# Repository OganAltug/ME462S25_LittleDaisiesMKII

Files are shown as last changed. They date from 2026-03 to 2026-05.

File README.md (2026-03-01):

Repository for ME462 - Mechatronics Design course at METU

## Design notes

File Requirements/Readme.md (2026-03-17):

Locking Mechanism:
- Mechanical:
  - The mechnism must be able to switch tools in less than 30 seconds.    
  - The mechanism must connect two sides without permanent fastening.
  - The mechanism must withstand axial load of 5kgs.
  - The mechanism must withstand torsional load of 6Nm.
  - The mechanism must withstand monment of 3Nm.
  - The mechanism must not shift more than 1 mm and 6 degrees in repetative usage.
  - The mechanism must allow manual disengage in less than 5 seconds in case of emergency.
  - The mechanism must be suitable to manufacture with basic robotics lab tools.
  - The mechanism must not disangage during the opertaion.
  - The total weight of the locking mechanism must be less than 2N (In Earth)
- Electrical Interface:
  - The mechanism must allow 23 consecutive hours of operation.
  - The electrical interface must carry the 8 electrical output of the Robot arm between two locking pieces.
  - The electrical interface should be modular on the robot side. (to adjust arms other than ur5)
  - The electrical interface must succesfully trasmit electricity for every engage.

Toolbox:
- Mechanical:
  - The toolbox must house more than 3 tool.
  - The Toolbox must hold the tools firmly.
  - The Toolbox must allow user to disengage tools less than 60 secs in manual operation.
  - The Toolbox must be in the reach of the robot arm.
  - The Toolbox position must be changeable.
  - The Toolbox must not block the motion of the robot arm.
- Electrical:
  - The Toolbox must be able to charge active grippers.
  - The Toolbox must prevent over-undercharge of the active tool batteries.
  - The Toolbox must indicate if the active gripper is charged or not to the user.
  - The Toolbox must communicate with the arm to inicate the charge status of the active grippers.
  - The Toolbox PCB must be maximum of two layers.
  - The Toolbox PCB components must be found in web less than 3 consecutive searches.

Handler:
- PCB:
  - The Handler PCB must have a port to connect Toolbox to charge itself.
  - The Handler must have a indicator to show its battery level to user.
  - The Handler must communicate with the arm to inicate the charge status of itself.
  - The Handler PCB must be maximum of two layers.
  - The Handler PCB must be smaller than 8x8 cm in size.
  - The handler PCB components must be found in web less than 3 consecutive searches.

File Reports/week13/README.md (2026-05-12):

# Weekly Report: LittleDaisiesMKII - Week 13

**Date Range:** May 5 - May 12
---
## 📊 Team Performance & Scoring

*Evaluation of specific tasks and deliverables based on project requirements.*
| Deliverable / Metric | Score | Notes |
| :--- | :--- | :--- |
| Robot control and sand writing  | 10/10 | We are able to write onto the sand  |
| Checking the new hardware given | 8/10 | Mini esp and the camera is checked  |
| Gripper force control | 7/10 | both force with current and fsr is tried|
| Image Processing | 5/10 | an object is followed via servo no updat eon arucos |
| TutanKhamun Gripper Assembly | 10/10 | TutanKhamun the Heybetli is Assembled |
| **Total Score**  | **40/50** | **Avg: 8/10** |
---

## 🤝 Meeting Notes

### May 11 - Group Meeting

**Key Discussion Points:**
Everyone is explained what they have done for the past week. 
* Buğra worked on image processing on Rasppery Pi, and successfully followed and object (human) by tip of the servo. He also tried to work with FSR, and sucessfully implemented the FSR force control to the 2f-85 gripper machanism. Finally, he tried to work with the given esp32 with integrated camera but did not like the output feed quality.
* Some search about the head is done.
  - [IDEA 1](https://www.youtube.com/shorts/ejHmpcbf4PA)<br>
  - [IDEA 2](https://www.youtube.com/shorts/wkof60aqg6w)<br>
  - [IDEA 3](https://www.youtube.com/shorts/eSnn20z8AxQ)<br>
  - [IDEA 4](https://www.youtube.com/watch?v=IT1uBUsOmUY)<br>
  - [IDEA 5](https://www.youtube.com/shorts/pm9Umdwg9uo)<br>
  - [IDEA 6](https://www.youtube.com/shorts/5SJYWTB2Nf4)<br>
  - [IDEA 7](https://youtube.com/shorts/Qu2Ccx3YggI?si=xmM9Od8_wPeU3PLN)<br>
  - [IDEA 8](https://youtube.com/shorts/5SJYWTB2Nf4?si=HgB3RJdVCw9v34qi)<br>
  - [IDEA 9](https://youtube.com/shorts/ARHM2iDbWIY?si=fSSAW8HbxofMi2Qx)<br>
  - [IDEA 10]<br>
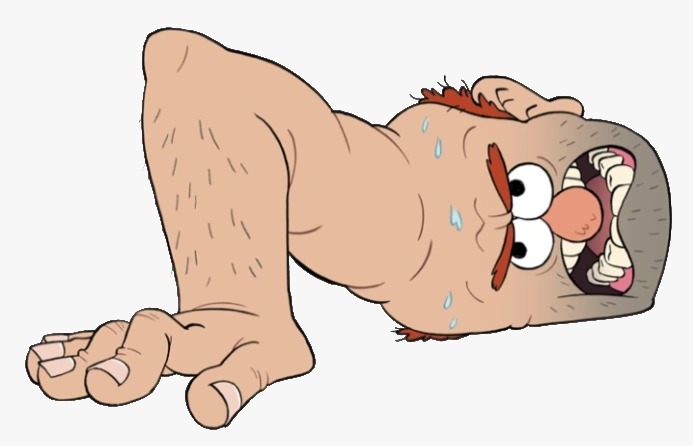
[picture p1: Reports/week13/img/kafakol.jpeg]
Kafa Kol
    <br>
  - [IDEA 11]<br>
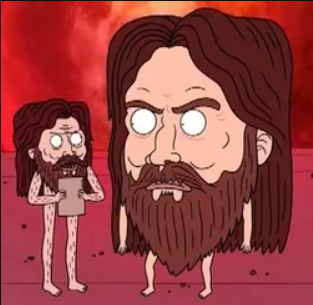
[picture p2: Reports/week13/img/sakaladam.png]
Sakal Adam
    
* Ogan kept working on the robot control. He finalized the sand-writing process, and now we are able to write on the sand. He also created a docker file for other members to efficiently and easiliy get into the robot control. Thanks Ogan.
* Naci kept wroking on the gripper mechanism, electronics and software. He mainly focussed on the force control via current readings, however he faced with some problems. Currently the current-force control is not as reliable as we wanted. He also gathered the documentations and files about the gripper so that other members of the group can succesfully get into the gripper part.
* Deniz, wrote this meeting minute.
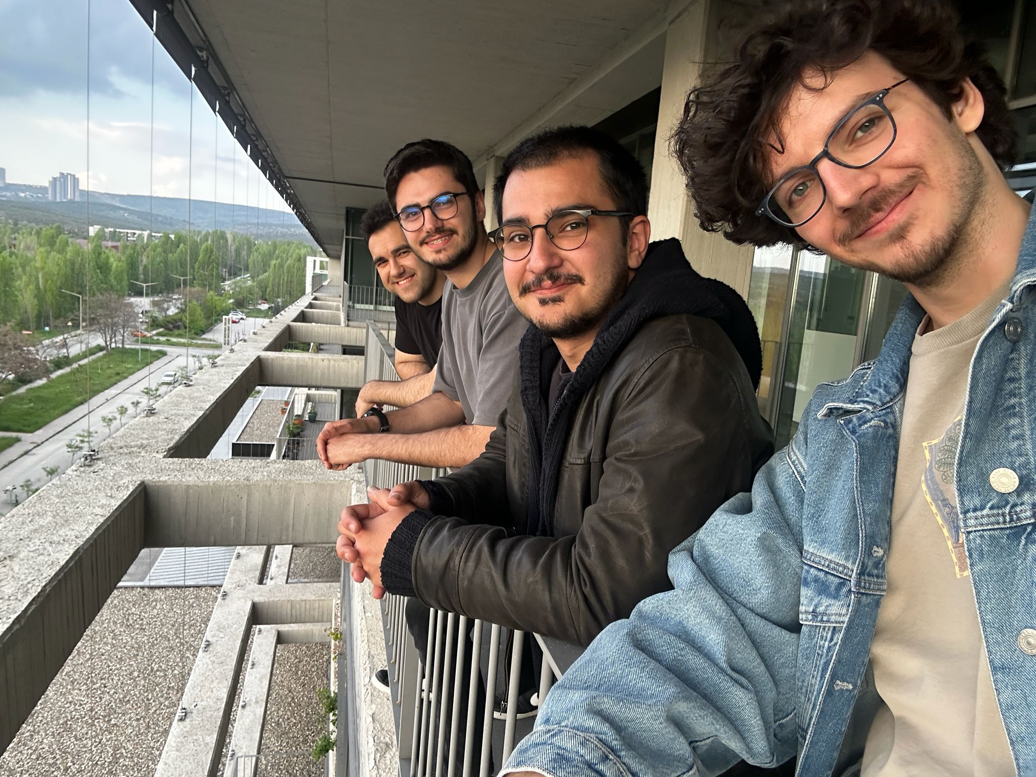
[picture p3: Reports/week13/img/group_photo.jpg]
Group Photo

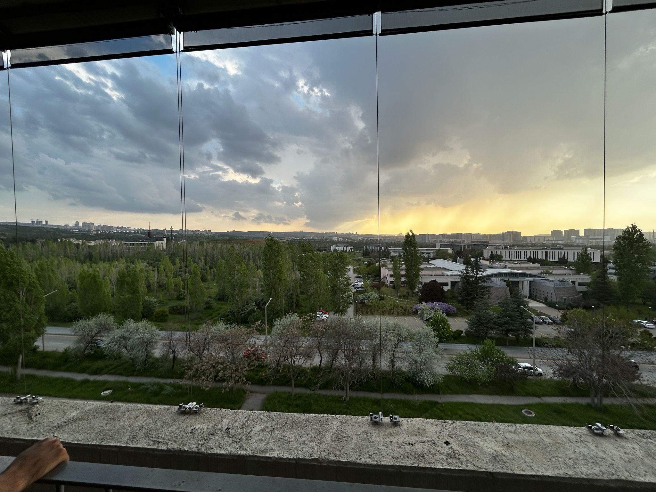
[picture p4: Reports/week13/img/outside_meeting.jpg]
Outside Meeting

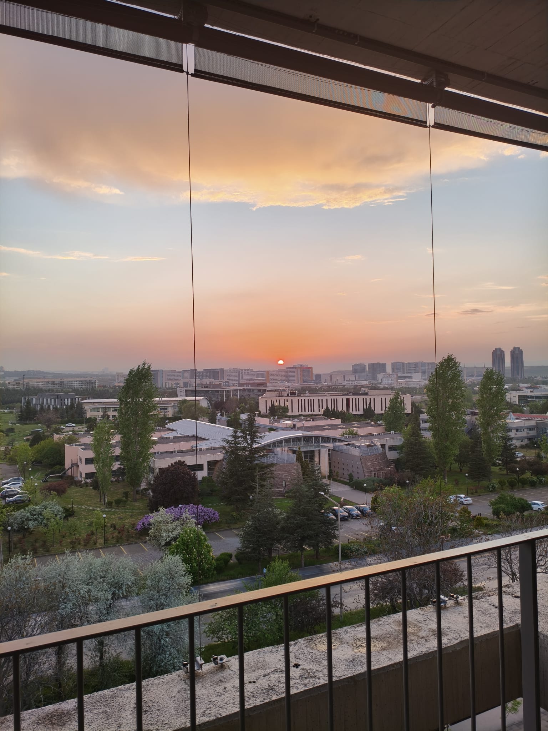
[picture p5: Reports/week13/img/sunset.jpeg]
Sunset

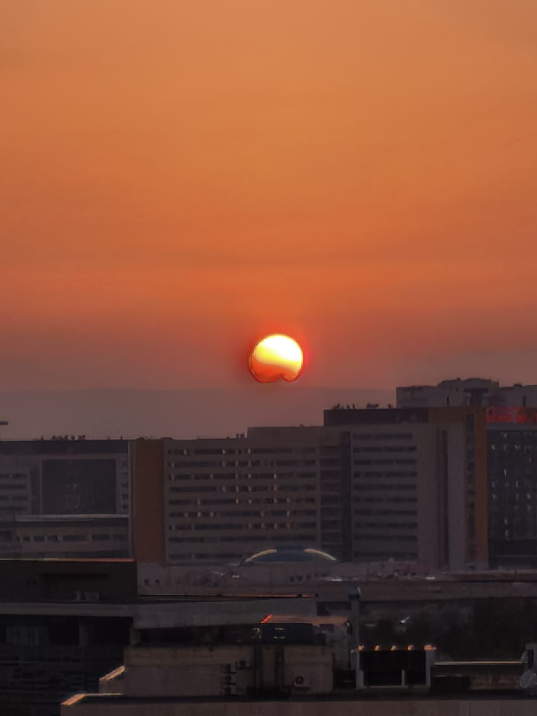
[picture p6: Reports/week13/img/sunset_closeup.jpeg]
Sunset Closeup

## 🖼️ Visual Documentation & Progress
* Writing Little Daisies on the sandpool
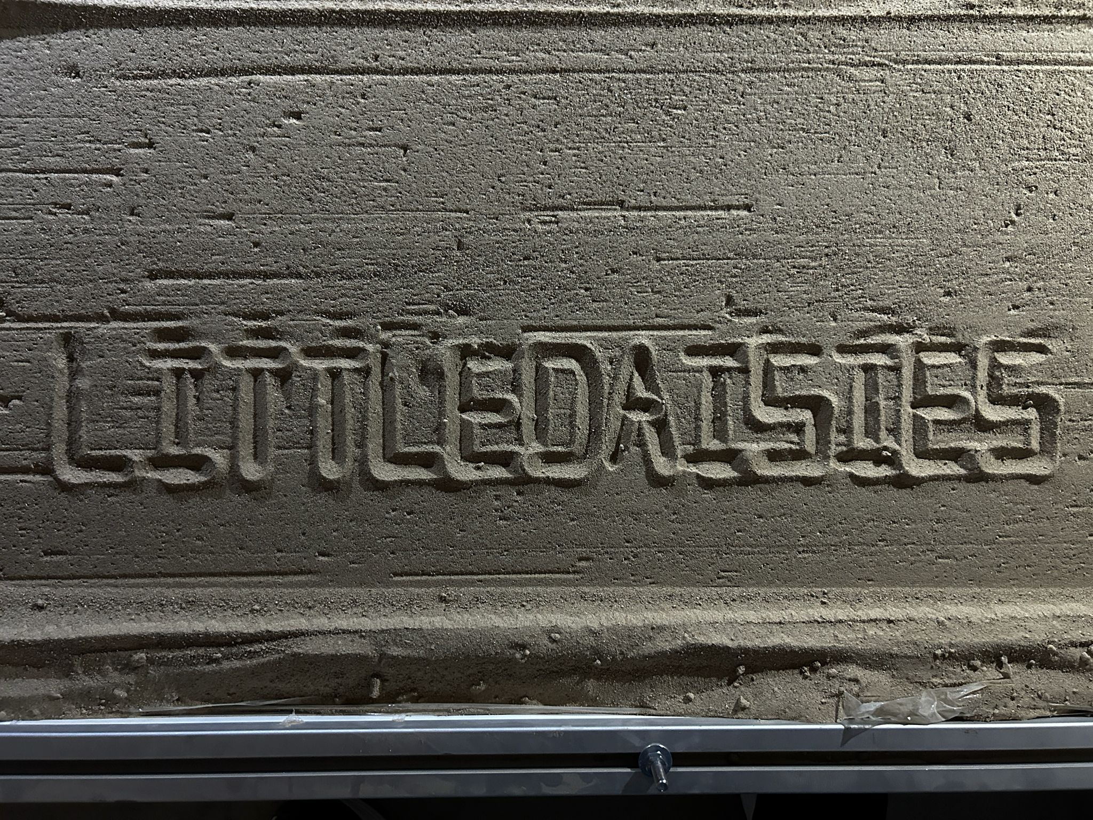
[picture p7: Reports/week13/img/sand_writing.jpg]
Little Daisies on the Sand

* Feed from esp32
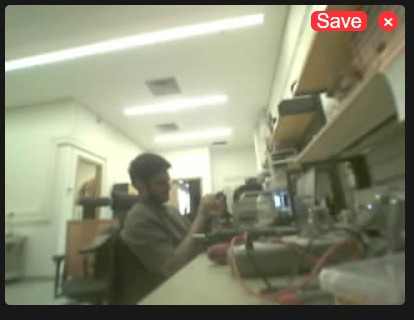
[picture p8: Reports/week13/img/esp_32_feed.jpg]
Feed from esp32

* Tutan Khamun Assembly
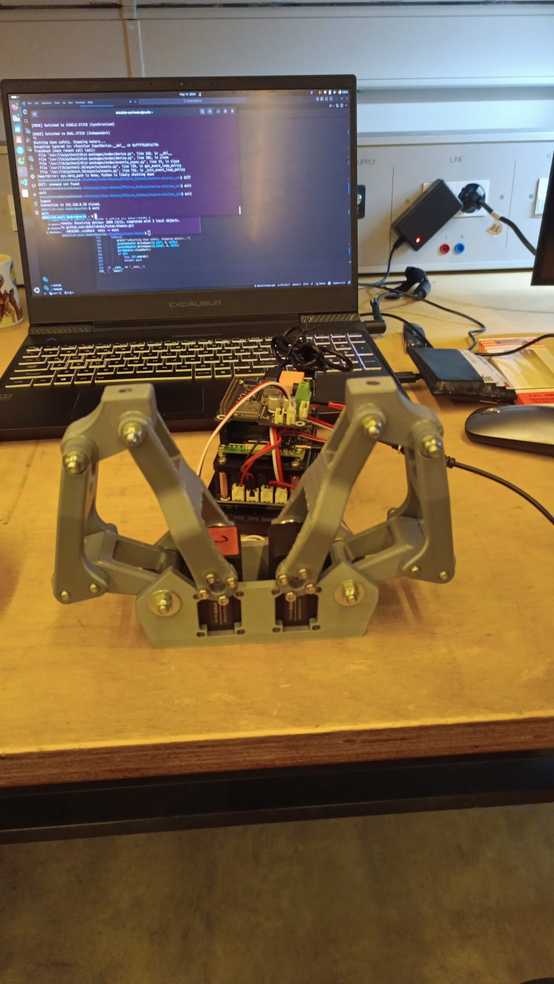
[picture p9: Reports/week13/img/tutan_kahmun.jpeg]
tutan_kahmun

* Plots from Tutan-Khamun current-force control
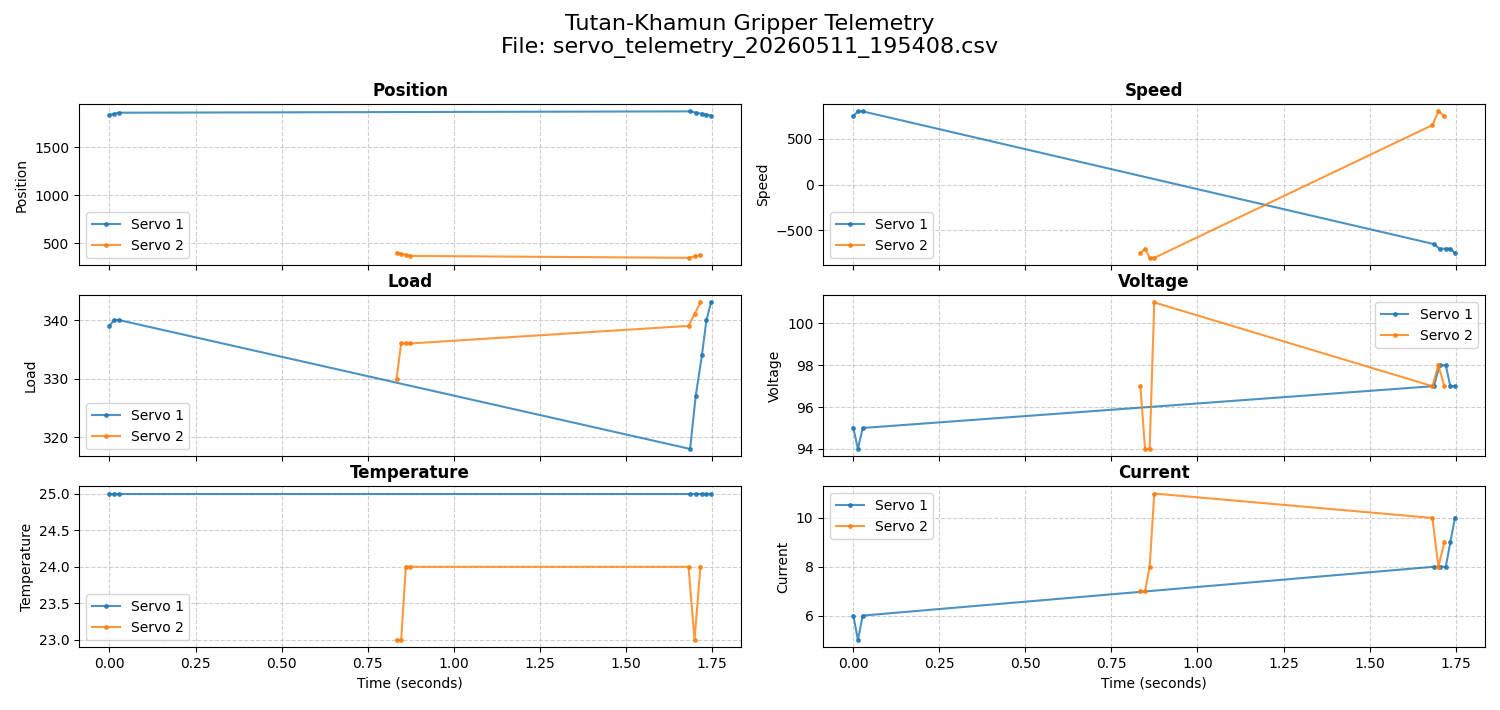
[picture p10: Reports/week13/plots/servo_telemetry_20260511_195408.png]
Only Threshold

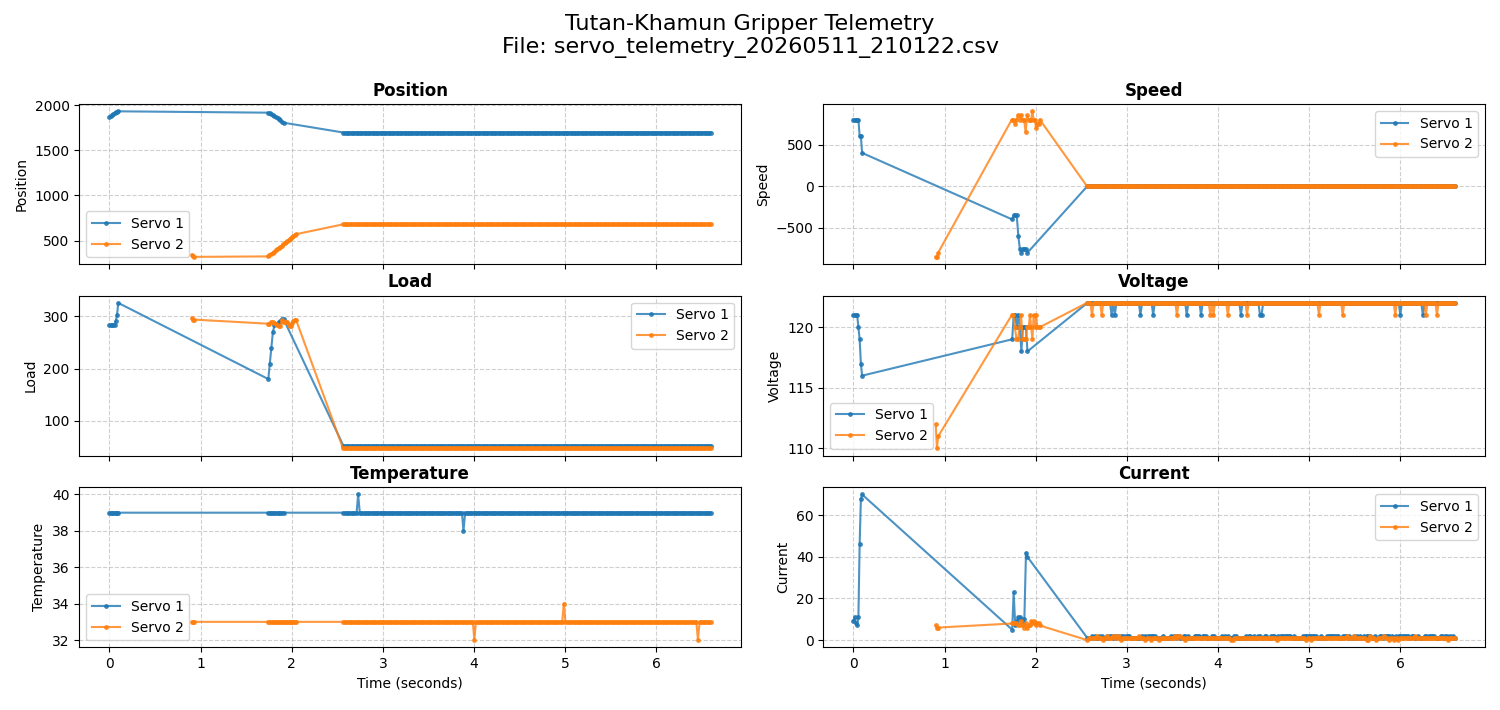
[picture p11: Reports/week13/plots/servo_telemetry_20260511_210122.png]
Delta Threshold

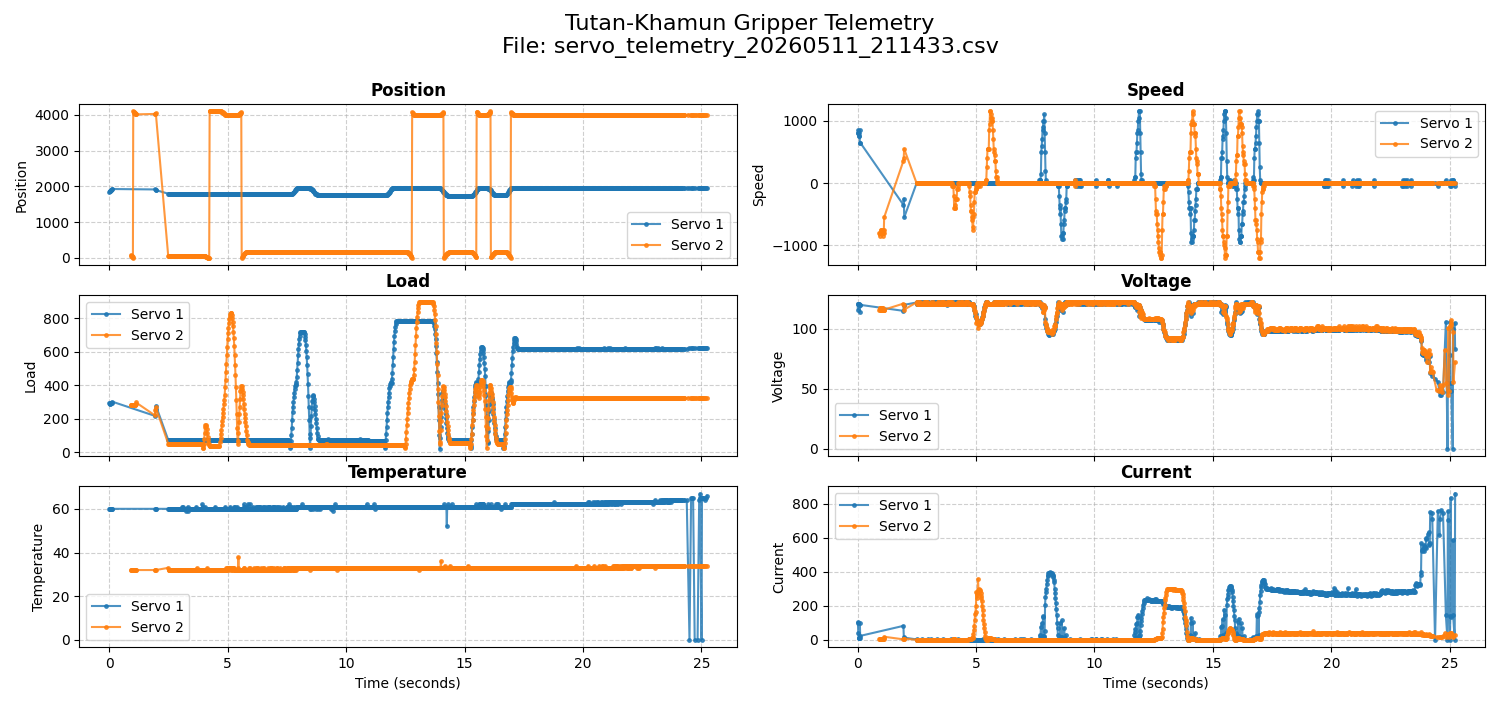
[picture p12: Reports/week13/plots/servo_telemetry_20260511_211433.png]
Burn-out


## 🔗 Documentation Links
[Robot Control Docker Repo](https://github.com/OganAltug/ME462ZenPoolWorkspace)

## 📝 To-Do List (Action Items)

### Immediate Priority

- [ ] **Hardware:** Redesign [Component] based on recent test results.
- [ ] **Software:** Implement [Feature] in simulation environment.
- [ ] **Manufacturing:** Obtain [Material/Part] and fabricate [Item].

### Research & Documentation

- [ ] **Research:** Investigate [Mechanism/Protocol] alternatives.
- [ ] **Reports:** Document [Naming Convention/Interface Requirements].
- [ ] **Maintenance:** Update README with latest links and media.

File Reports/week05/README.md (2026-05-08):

# Weekly Report: LittleDaisiesMKII - Week 5

**Date Range:** March 10 - March 16, 2026

## 📊 Team Performance & Scoring

*Evaluation of specific tasks and deliverables based on project requirements.*

| Deliverable / Metric | Score | Notes |
| :--- | :--- | :--- |
| Naming Convention | 6/10 | Revision in progress |
| Meeting Minutes | 10/10 | Completed |
| Locking Interface PCB Requirements | 5/10 | Further detail needed |
| Locking Interface Mech. Requirements | 8/10 | Well-defined |
| Robot Control | 7/10 | Progressing |
| Zen Tool (Rotated by π/2) | 8/10 | Design and manufacturing |
| **Total Score** | **44/60** | **Avg: 7.33/10** |

---

## 🤝 Meeting Notes

### Monday Meeting

**Key Discussion Points:**

* **Decisions:** Naming convention finalized and documented via visual reference.
* **Hardware Progress:** Designed and manufactured the first version of the Zen Tool; designed a sieve for the tool.
* **Simulation & Control:** Successfully tested basic UR5e pose-to-pose motion using MuJoCo and Robotictoolbox.
* **Manufacturing:** Discussed laser-cut PCB manufacturing details, including Xtool and KiCAD settings and via manufacturing ideas.
* **Mechanism Brainstorming:** Evaluated kinematic coupling ideas including self-releasing grapples, bearing-style ball locks, and active locking via the UR5e power cable.

### Tuesday Meeting

* **Electronic Specs:** Researched microcontroller features including Wi-Fi support, deep-sleep modes, and Wi-Fi wake capabilities.
* **Communication:** Initiated review of communication protocols.

---

## 🖼️ Visual Documentation & Progress

*Capturing hardware builds and simulation results.*

* **Naming Convention:**
  `<img src="./img/name_convention.jpeg" alt="Name Convention" width="600"/>`
* **Zen Tool Mounted:**
  `<img src="./img/ZenToolMounted.jpeg" alt="ZenToolMounted" width="300"/>`
* **Sieve Design:**
  `<img src="./img/sieve.jpeg" alt="Sieve Design" width="300">`
* **MuJoCo Simulation:**
  `<img src="./img/mujoco.gif" alt="Mujoco Sim" width="400">`

---

## 🔗 Documentation Links

* [Tool Interface/Handler Requirements](../../Requirements/Readme.md)
* [PCB Manufacturing Report](../../PCB/HowToLaserPCB.md)
* [Locking Mechanism Ideas (Google Doc)](https://docs.google.com/document/d/15yzl3hxYkYvtqdlGrBOaPBBX_cD7uZbD/edit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)

---

## 📝 To-Do List (Action Items)

### Immediate Priority

- [ ] **Hardware:** Redesign/tweak Zen Tool based on structural and functional testing.
- [ ] **Hardware:** Manufacture sieve (obtain wire first).
- [ ] **Software:** Implement Zen Tool into MuJoCo and test.
- [ ] **Electronics:** Research PCB components and UR5e serial connection details.

### Research & Documentation

- [ ] **Research:** Look into alternative simulators and quick connect/release mechanisms.
- [ ] **Reports:** List all potential locking mechanisms in a dedicated file and write interface requirements.
- [ ] **Maintenance:** Document the naming convention and add links to the "README.md".

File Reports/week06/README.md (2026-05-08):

# Weekly Report: LittleDaisiesMKII - Week 6

**Date Range:** March 17 - March 23, 2026

## 📊 Team Performance & Scoring

*Evaluation of specific tasks and deliverables based on project requirements.*

| Deliverable / Metric | Score | Notes |
| :--- | :--- | :--- |
| Meeting Minutes | 10/10 | Completed |
| Communication Protocols | 0/10 | Not discussed yet |
| Numeric Proofs for Design Choices | 0/10 | Pending for decision matrix justification |
| Toolbox & Locking Requirements (Mech) | 8/10 | Concepts generated; full brainstorm pending |
| Toolbox & Locking Requirements (Elec) | 0/10 | Toolbox not yet discussed |
| Artsy Tool First Design | 5/10 | Designs exist; no progress this week |
| Tweak & Manufacture Design | 5/10 | Printed model exists; improvements pending  |
| **Total Score** | **28/70** | **Avg: 4.0/10 (Ramadan Fest)** |

---

## 🤝 Meeting Notes

### Monday Meeting

**Key Discussion Points:**

* **Decisions:** Documented naming convention and compiled a comprehensive list of locking mechanisms.
* **Mechanism Brainstorming:** Focused on passive locking mechanism drafts (Ogan, Naci, Buğra, and Ahmet's ideas). Passive ideas are prioritized to determine if they suffice before moving to active systems.
* **Review:** Inspected individual team member concepts to prepare for the upcoming decision matrix.

### Tuesday Meeting

* **Design Ideas:** Explored magnetic locking (strong tensile, weak shear) and ball magnets for Buğra’s Design II.
* **Toolbox Concepts:** Discussed a non-rigidly attached toolbox using camera-based position detection.
* **Mechanical Innovation:** Discussed a reusable "dübel" concept and a 90-degree movement version of the push-to-turn design.
* **Future Outlook:** Initiated preliminary talk on active grippers.

---

## 🖼️ Visual Documentation & Progress

*Capturing hardware builds and simulation results.*

* **Current Prototype:**
  `<img src="./img/printed_model.jpeg" alt="Printed Model" width="300"/>`
* **Locking Concepts:**
  `<img src="./img/locking_drafts.jpeg" alt="Locking Mechanism Drafts" width="600"/>`

---

## 🔗 Documentation Links

* [Naming Convention Document](../../Requirements/NamingConvention.md)
* [Locking Mechanisms List](../../Requirements/LockingMechanisms.md)
* [Brainstorming Minutes](../../Minutes/BrainstormingNotes.md)

---

## 📝 To-Do List (Action Items)

### Immediate Priority

- [ ] **Hardware:** Manufacture the Zen tool sieve (obtain wire first).
- [ ] **Control:** Start controlling the robot arm.
- [ ] **Analysis:** Conduct the decision matrix for the generated locking drafts.
- [ ] **Design:** Finalize passive locking requirements and final drafts.

### Research & Documentation

- [ ] **Strategic:** Depending on decision matrix, start toolbox requirements OR generate active locking ideas.
- [ ] **Manufacturing:** Manufacture a full set of Zen tools.
- [ ] **Brainstorming:** Set toolbox ideas once requirements are finalized.

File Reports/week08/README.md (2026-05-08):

# Weekly Report: LittleDaisiesMKII - Week 8

**Date Range:** March 31 - April 6, 2026

---

## 📊 Team Performance & Scoring

*Evaluation of specific tasks and deliverables based on project requirements.*

| Deliverable / Metric | Score | Notes |
| :--- | :--- | :--- |
| Robot Arm Control | 7/10 | Simulations started; UR5 testing with Zen tool |
| Locking Mechanism Trial / DoveTail | 4/10 | Dovetail/pin printed; wedge/ball design ready  |
| Zen Tool Trial | 8/10 | Controlled UR5 with Zen tool |
| **Total Score** | **19/30** | **Avg: 6.33/10** |

---

## 🤝 Meeting Notes

### Weekly Progress

**Key Discussion Points:**

* **Robot Arm Control:** Ogan initiated simulation work [cite: 5]. Ahmet Deniz performed physical testing using the Zen tool and the UR5 arm
* **Mechanism Development:** The dovetail and pin locking mechanism was printed and tested for initial fit and function
* **New Designs:** A wedge-based locking mechanism utilizing a ball/bearing was successfully designed
* **Zen Tool Integration:** Demonstrated successful control of the UR5 system specifically utilizing the Zen tool interface

---

## 📝 To-Do List (Action Items)

### Immediate Priority

- [ ] **Control:** Continue progress on Robot Arm Control systems.
- [ ] **Design:** Perform optimization of the Dovetail & Pin Locking Mechanism.
- [ ] **Development:** Create an initial design for the tool box based on the current locking mechanism for simple testing.

### Research & Documentation

- [ ] **Testing:** Prepare simple testing procedures for the new toolbox design.

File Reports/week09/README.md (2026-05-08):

# Weekly Report: LittleDaisiesMKII - Week 9

**Date Range:** April 7 - April 13, 2026

---

## 📊 Team Performance & Scoring

*Evaluation of specific tasks and deliverables based on project requirements.*

| Deliverable / Metric | Score | Notes |
| :--- | :--- | :--- |
| Robot Arm Control | 9/10 | Progress in simulations; documentation hurdles |
| Locking Mechanism Optimization | 10/10 | Concept nearly finalized and optimized |
| Initial Toolbox Design | 8/10 | Multiple concepts designed; charging research done |
| **Total Score** | **27/30** | **Avg: 9.0/10** |

---

## 🤝 Meeting Notes

### Weekly Progress

**Key Discussion Points:**

* **Robot Arm Control:** Ogan continued simulation progress, though limited documentation for MuJoCo and ROS has presented challenges. Potential shifts to C++ may be required.
* **Mechanism Optimization:** Deniz further refined the dovetail and pin locking mechanism, nearly finalizing the concept. Buğra proposed an alternative pin system designed for better charging connectivity.
* **Toolbox Design:** Naci and Buğra developed separate toolbox concepts, with Buğra’s design featuring rotational springs and moving arms for stability.
* **Charging Investigations:** Evaluated Pogo pin connectors (favored for ease of control), wireless Magsafe-style chargers (financial and alignment concerns), and standard cable connectors (rejected due to high precision requirements).

---

## 🖼️ Visual Documentation & Progress

*Capturing hardware builds and simulation results.*

### 🎥 Media (Videos)

* **Arm Control Simulation:**
  [Video 1](./media/armcontrol_ogan.mp4)
* **Locking Mechanism Optimization:**
  [Video 1](./media/locking_deniz1.mp4)
  [Video 2](./media/locking_deniz2.mp4)

### 📷 Images

* **Optimized Locking Pin:**
  `<img src="./img/locking_deniz3.jpeg" alt="locking_deniz3" width="320"/>`
* **Naci's Toolbox Concept:**
  `<img src="./img/locking_bugra1.jpeg" alt="toolbox_naci" width="320"/>`
* **Buğra's Toolbox Design:**
  `<img src="./img/locking_bugra2.jpeg" alt="locking_bugra2" width="320"/>`

---

## 🔗 Documentation Links

* [Toolbox Charging Research](../../Research/ChargingOptions.md)
* [Dovetail Finalization Report](../../Design/DovetailFinal.md)
* [Active Tool Concepts](../../Design/ActiveTools.md)

---

## 📝 To-Do List (Action Items)

### Immediate Priority

- [ ] **Control:** Dedicate more effort to Robot Arm control to overcome documentation hurdles.
- [ ] **Testing:** Test the first toolbox version using the final locking mechanism version.
- [ ] **Design:** Update the mechanical systems of the toolbox based on test results.
- [ ] **Research:** Conduct further searches and discussions regarding charging integration.

### Research & Development

- [ ] **Active Tools:** Discuss and search for active tool implementations (e.g., tracking eye, grippers, or "torNA") to assign PCB specifications.

* **Active Tool References:**
  `<img src="./img/tornaci1.png" alt="torNACİ" width="100"/>` `<img src="./img/tornaci2.png" alt="torNACİ" width="100"/>` `<img src="./img/tornaci3.png" alt="torNACİ" width="100"/>`

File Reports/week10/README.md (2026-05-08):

# Weekly Report: LittleDaisiesMKII - Week 10

**Date Range:** April 14 - April 20, 2026

---

## 📊 Team Performance & Scoring

*Evaluation of specific tasks and deliverables based on project requirements.*

| Deliverable / Metric | Score | Notes |
| :--- | :--- | :--- |
| Robot Arm Control | 8/10 | Ongoing effort; requires more time than expected |
| Toolbox Testing & Updates | 8/10 | Mechanical updates following locking mechanism finalization; charging research ongoing |
| Active Tool Research | 9/10 | Extensive brainstorming and tier-listing of concepts |
| **Total Score** | **25/30** | **Avg: 8.33/10** |

---

## 🤝 Meeting Notes

### 17.04.2026 Meeting

**Key Discussion Points:**

* **Design Ideas:** Discussed Buğra's arm design with springs (focus on buckling) and Ogan's toolbox design with pins.
* **Analysis:** Examined the springback effect of the button.
* **New Concept:** Deniz presented a new tool-changer design utilizing magnets and pins.

### 18.04.2026 Meeting

* **Toolbox Design:** Buğra's design was drawn; Naci updated arm alignment for better performance.
* **Drafting:** Deniz tasked with drawing Ogan's pin-based idea.
* **Simplified Locking:** Buğra proposed a simpler magnetic locking mechanism alternative to the wedge design.

### 20.04.2026 Meeting

* **Concept Brainstorming:** Discussed a wide variety of interactive scenarios:
  * **Zen Sand Artist:** Drawing in sand with a hologram display and recorded tool changes.
  * **Combat/Defense:** Nerf gun defense for sand art, laser "gunslinger" duels, and dart shooting.
  * **Creative/Utility:** Model-making (cutting/gluing), soldering, painting wands, and casino Blackjack dealing.
  * **Personality:** The "Frustrated Organizer" that puts items back or shoots if moved repeatedly.

---

## 🖼️ Visual Documentation & Progress

*Capturing hardware builds and simulation results.*

### 🎥 Media (Videos)

* **Pin Tool Change Test:**
  [Video 1](./media/pin_tool_change.mp4)

### 📷 Images

* **Deniz's Magnet-Pin Concept:**
  `<img src="./img/meet0.png" alt="Magnet Pin Concept" width="320"/>`
* **Buğra's Simple Magnetic Changer:**
  `<img src="./img/bugra_magnet_toolchanger.jfif" alt="Magnetic Changer" width="320"/>`
* **Naci & Team Meeting Logs:**
  `<img src="./img/meet1.jpg" alt="Meeting Note 1" width="320"/>` `<img src="./img/meet2.jfif" alt="Meeting Note 2" width="320"/>`
* **Active Tool Tier List:**
  `<img src="./img/tierlist.png" alt="Tier List" width="320"/>`

---

## 🏗️ Active Tool Design Ideas

A collection of existing and proposed concepts for tool integration:

* **Existing Ideas:** Dragon head fire, lightsaber, Nerf/Nail gun, car-carrying tool.
* **Mechanical Systems:** Hitting mechanisms (Rack & Pinion with spring release), paper cutting (distance measurement & slicing), and sandpaper tools.
* **Grippers:** Adaptive fingers, magnetic, vacuum, and insertion tools.
* **Interactive:** UI screens for Romer navigation and passive tools like kalem/pens for UR5 angle drawings.

## 📝 To-Do List (Action Items)

### Immediate Priority

- [ ] **Hardware:** Update mechanical toolbox designs and perform testing with the final locking mechanism.
- [ ] **Charging:** Continue research and final discussion on toolbox charging integration.
- [ ] **Control:** Dedicate more effort to Robot Arm Control progress.

### Research & Development

- [ ] **PCB Specs:** Assign PCB specifications based on selected active tools.
- [ ] **Manufacturing:** Continue "torNA" progress (Naci).

* **torNA Status:**
  `<img src="./img/tornaci.png" width="80"/>` `<img src="./img/tornaci2.jfif" width="80"/>` `<img src="./img/tornaci3.jfif" width="80"/>` `<img src="./img/tornaci4.png" width="80"/>`

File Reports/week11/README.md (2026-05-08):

# Weekly Report: LittleDaisiesMKII - Week 11

**Date Range:** April 21 - April 27, 2026

---

## 📊 Team Performance & Scoring

*Evaluation of specific tasks and deliverables based on project requirements.*

| Deliverable / Metric | Score | Notes |
| :--- | :--- | :--- |
| Active Tool Discussion | X/10 | One tool decided (Face/Eye); second tool in discussion |
| Gripper Design & Print (Naci)  | X/10 | Includes Raspberry Pi 4 integration |
| Zen Tool Prototyping (Ogan) | X/10 | Printed versions with locking interface |
| Toolbox Iteration (Deniz) | X/10 | Handled problems and printed new version |
| Fixed Toolbox Testing | X/10 | Successful test of fixed configuration |
| Toolbox Configuration Tests | X/10 | Ogan tested different configurations |
| Kinematic Derivations (Buğra) | X/10 | Loop closure relations and source code added |
| **Total Score** | **X/70** | **Avg: X.XX/10** |

---

## 🤝 Meeting Notes

### 27.04.2026 Meeting

**Key Discussion Points:**

* **Active Tool Decisions:** Decided on a Face/Eye following mechanism (Mechanical or LCD) as the first tool.
* **Brainstorming:** Discussed options for the second tool, including a Nerf-like shooting mechanism, utility tools (scissors/drill), or advanced grippers like the "bubble gripper" or octopus-style adaptive fingers.
* **Timeline:** Project pace will accelerate over the next two weeks to account for şenlik and upcoming exams.
* **Key Assignments:**
  * **Naci:** Finalize gripper and develop electrical interface/Pico code
  * **Deniz & Buğra:** Focus on image processing using Raspberry Pi 4.
  * **Ogan:** Implement robot control using custom arm movement codes.
  * **Infrastructure:** Finalize and fix the toolbox position.

---

## 🖼️ Visual Documentation & Progress

*Capturing hardware builds and simulation results.*

### 🎥 Media (Videos)

* **Fixed Toolbox Test:** [Video 1](./media/tool_box_video1.mp4)
* **Configuration Testing:** [Video 2](./media/tool_box_video2.mp4)

### 📷 Images

* **Gripper Mechanism:** `<img src="./img/gripper1.png" alt="Gripper Mechanism" width="200"/>`
* **Zen Tool Interface:** `<img src="./img/zen.jpeg" alt="Zen Tool" width="200"/>`
* **Toolbox Progress:** `<img src="./img/tool_box.jpeg" alt="Toolbox" width="200"/>`
* **Kinematic Derivations:** `<img src="./img/derivation1.png" width="160"/>` `<img src="./img/derivation2.png" width="160"/>` `<img src="./img/derivation3.png" width="160"/>`[cite: 5]

---

## 🔗 Documentation Links

* [Face/Eye Reference](https://www.youtube.com/shorts/ZUmvmScEfdM)
* [Kinematic Relation Source Code (KinematicRelation.py)](KinematicRelations.py)
* [Bubble Gripper Research](https://punyo.tech/bubble-gripper.html)

---

## 📝 To-Do List (Action Items)

### Immediate Priority

- [ ] **Hardware:** Naci to finalize the gripper mechanism.
- [ ] **Electronics:** Progress the electrical interface and Pico-based controls.
- [ ] **Software:** Deniz & Buğra to implement image processing on Raspberry Pi 4.
- [ ] **Control:** Ogan to test arm movement with internal robot control codes.
- [ ] **Integration:** Fix the toolbox in its final decided position.

### Research & Development

- [ ] **Control:** Aim to control the robot arm via image processing feedback.
- [ ] **torNA Progress:** Continue development on the "torNA" system.

* **torNA Gallery:** `<img src="./img/tornaci1.png" width="100"/>` `<img src="./img/naci1.jpeg" width="100"/>` `<img src="./img/naci2.jpeg" width="100"/>`

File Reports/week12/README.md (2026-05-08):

# Weekly Report: LittleDaisiesMKII - Week 12

* **Date Range:** April 28 - May 4, 2026

---

## 📊 Team Performance & Scoring

*Evaluation of specific tasks and deliverables based on project requirements.*

| Deliverable / Metric | Score | Notes |
| :--- | :--- | :--- |
| Gripper Mechanism | X/10 | |
| Electrical Interface and Pico-Based Control | X/10 | |
| Image Processing on Raspberry Pi 4 | X/10 | |
| Robot Control via code | X/10 | |
| ToolBox position | X/10 | |
| **Total Score** | **X/60** | **Avg: X.XX/10** |

---

## 🤝 Meeting Notes

### [May 3, 2026] - Group Meeting

### **Key Discussion Points:**

* For technical sync, everyone mentioned what they have  done until the meeting. We did discuss what we will do untill the tuesday meeting and gather some thoughts about the ideas.
  <<<<<<< HEAD
* Deniz did some work on camera calibration via charuco markers and mentioned about it. He says that on the xy plane, there were errors but in the dept measurements, it was quite okay.
* Buğra mentioned that whether we need precise camera coordinate or what since we only tell if there is human and track him or play tick tack toe in the known space with robotic arm.
* Deniz mentioned that it would be a trouble when the camera does not see aruco markers. Follow ups were suggested:

  - We can use the fixed object to calculate the camera point in the space.
  - We can implement multiple aruco markers to the fixed points in the lab.
  - We can use 360 camera for the image processing.
* Ogan's written code worked on simulation but it does not go to the wanted locations.
* He will get time with the parameters and will read the documentation for therobot to write it from the scratch.
* Buğra mentions his trouble with the rasp pi 4. One of the machine has not a power hub and one of them did not even start booting.
* Naci mentioned what he did on this week. He mentioned about the problems he encountered during the control of the servos.
* Naci explains the electronic structure of the gripper **Tutan-Khamun** . We will use rasp pi 4 for the servo control and feedbacks. Maybe in the future, we can use esp32 or even pi pico to control the ST3215 servos. Our servo driver is not an efficient way of drive the servos.

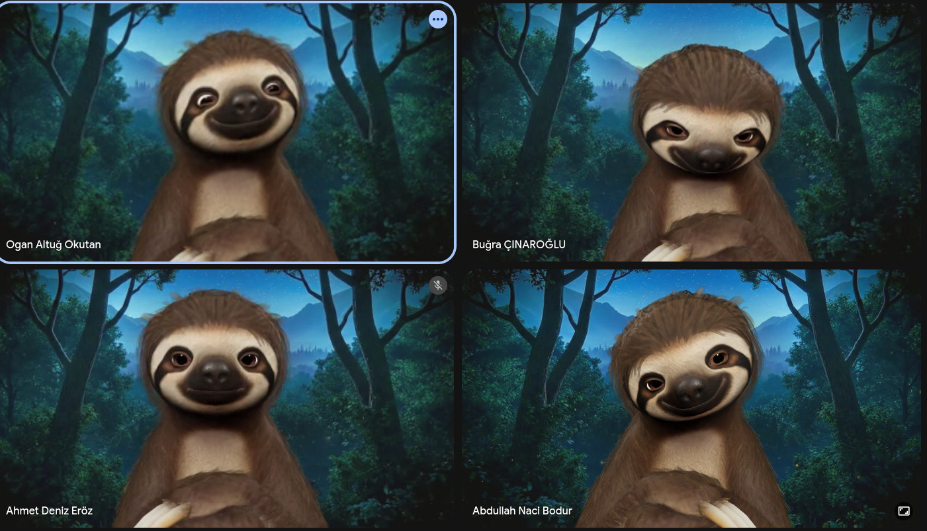
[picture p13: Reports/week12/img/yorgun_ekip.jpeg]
Yorgun Ekip

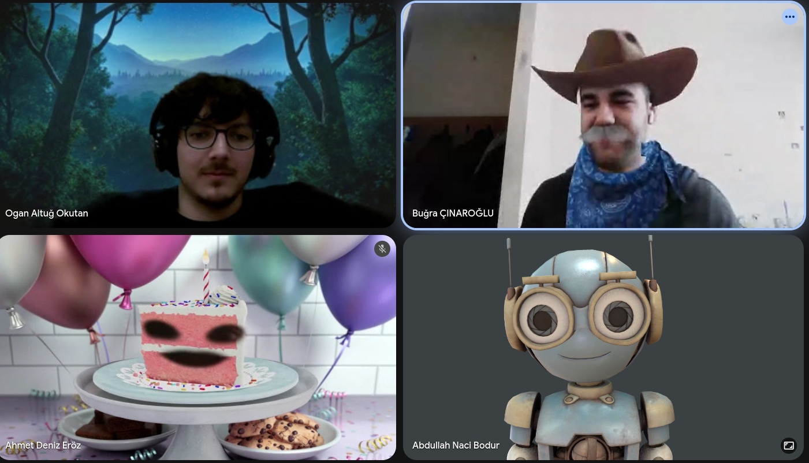
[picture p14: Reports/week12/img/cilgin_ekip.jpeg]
Cilgin Ekip

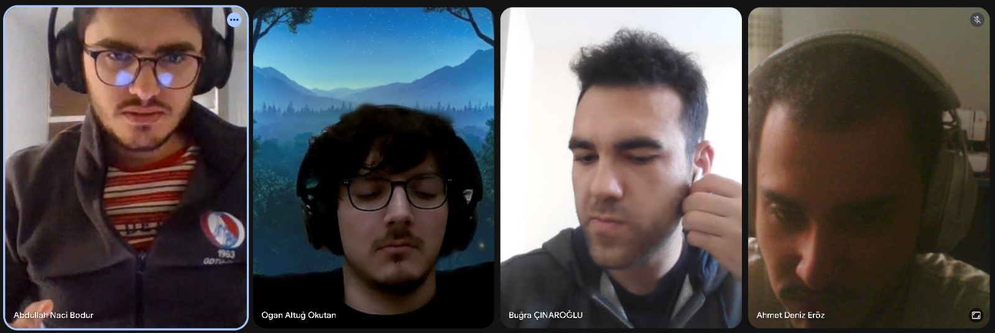
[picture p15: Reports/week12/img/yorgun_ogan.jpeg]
Yorgun Ogan

=======

* Deniz did some work on camera calibration via charuco markers and mentioned about it. He says that on the xy plane, there were errors but in the dept measurements, it was quite okay.
* Buğra mentioned that whether we need precise camera coordinate or what since we only tell if there is human and track him or play tick tack toe in the known space with robotic arm.
* Deniz mentioned that it would be a trouble when the camera does not see aruco markers. Follow ups were suggested:

  - We can use the fixed object to calculate the camera point in the space.

  - We can implement multiple aruco markers to the fixed points in the lab.

  - We can use 360 camera for the image processing.
* Ogan's written code worked on simulation but it does not go to the wanted locations.
* He will get time with the parameters and will read the documentation for therobot to write it from the scratch.
* Buğra mentions his trouble with the rasp pi 4. One of the machine has not a power hub and one of them did not even start booting.
* Naci mentioned what he did on this week. He mentioned about the problems he encountered during the control of the servos.
* Naci explains the electronic structure of the gripper **Tutan-Khamun** . We will use rasp pi 4 for the servo control and feedbacks. Maybe in the future, we can use esp32 or even pi pico to control the ST3215 servos. Our servo driver is not an efficient way of drive the servos.

Yorgun Ogan
Yorgun Ekip
Cilgin Ekip

**Untill tuesday meeting:**

* Deniz will getting better results in calibration.Deniz will provide data for the errors he encountered in xy plane and depth.
* Deniz will move his setup [his pc with windows] to rasp pi ubuntu 22.04.
* Deniz maybe will try to use 360 camera.
* Buğra will try to boot rasp pi 4 and install ras 2 humble [We will all use ros 2 humble]
* Ogan will write the code for the robot control.
* Ogan will write **ROMER** to the sand using code, if he fails he will do it by hardcoding.
* Naci will write a demo for the st3215 servos by using Bus Servo Driver Hat A from the laptop with python.
* Naci will print 1.5/1 scale gripper Tutan-Khamun and assemblies it.
* Deniz will provide data for the errors he encountered in xy plane and depth.
* Deniz will move his setup [his pc with windows] to rasp pi ubuntu 22.04.
* Deniz maybe will try to use 360 camera.
* Buğra will try to boot rasp pi 4 and install ras 2 humble [We will all use ros 2 humble]
* Ogan will write the code for the robot control.
* Ogan will write **ROMER** to the sand using code, if he fails he will do it by hardcoding.
* Naci will write a demo for the st3215 servos by using Bus Servo Driver Hat A from the laptop with python.
* Naci will print 1.5/1 scale gripper **Tutan-Khamun** and assemblies it.
* Naci will assembly the electronics to show the setup. ( Since we are short in st3215 servos, we will not provide the actual setup. Both of them will be seperate.)

---

### April 28 - May 02, 2026 - Follow-up / Technical Sync

* **April 28:** Completed the parametric design of the active tool **Tutan-Khamun**. All mechanical CAD files and servo control source codes have been organized within the project repository.
* **April 29 - April 30:** Developed servo control logic. Testing was conducted to drive servos via Pi Pico; however, due to efficiency concerns and timeline constraints, the system was transitioned to Raspberry Pi 4 control.
* **April 30:** Successfully moved the robot arm using custom control code. Additionally, a permanent position for the toolbox was established and maintained on the platform.

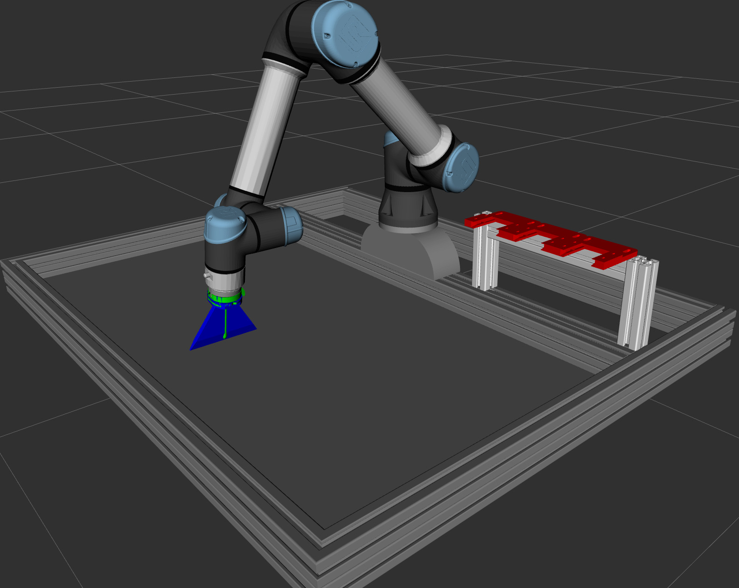
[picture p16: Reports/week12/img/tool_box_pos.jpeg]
  
* **May 1:** Ogan suggested that we should chose [this](https://youtu.be/pQ2dI_B_Ycg?si=ietTri2PLfs5GCBM "bıcak_ceken_kol") as an active tool.
* **May 1:** Deniz made camera calibration via **Charuco** markers. In every lighting changes, he needed to calibrate the cameras according to the calibration pattern.
* **May 02:** Conducted hardware diagnostics and image processing development. Image processing was implemented using **MediaPipe**, while Raspberry Pi 4 booting was attempted for system integration.

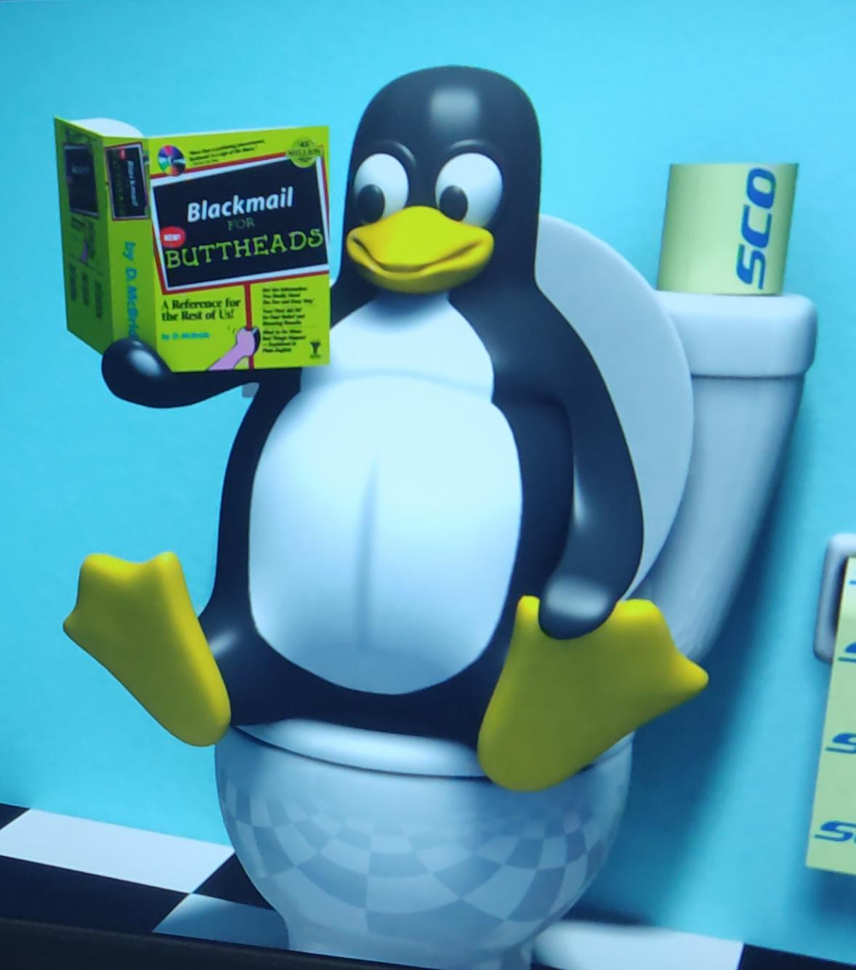
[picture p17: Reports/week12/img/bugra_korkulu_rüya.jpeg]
  
* **Electronic Specs:** Finalized the compact electronics case design. The system integrates a **Waveshare 3S UPS Module** to provide regulated power (3V, 5V, 12V for servos), a shared ground, a kill switch, and a dedicated charging jack.

#### Media Documentation

* **Toolbox Positioning & Arm Movement:**
  [Video 1](./media/robot_control_code.mp4)
* **Tutan-Khamun Mechanics:**

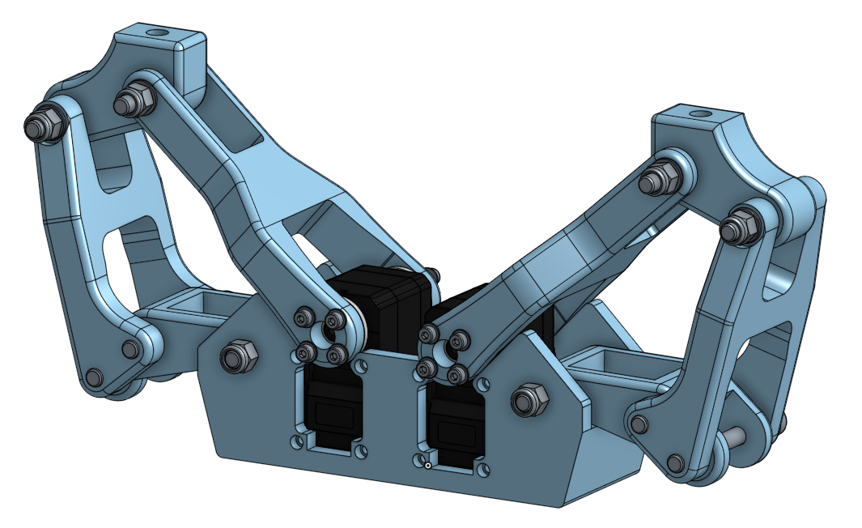
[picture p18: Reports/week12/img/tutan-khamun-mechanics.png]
Mechanic
  
* **Tutan-Khamun Electronics Case:**

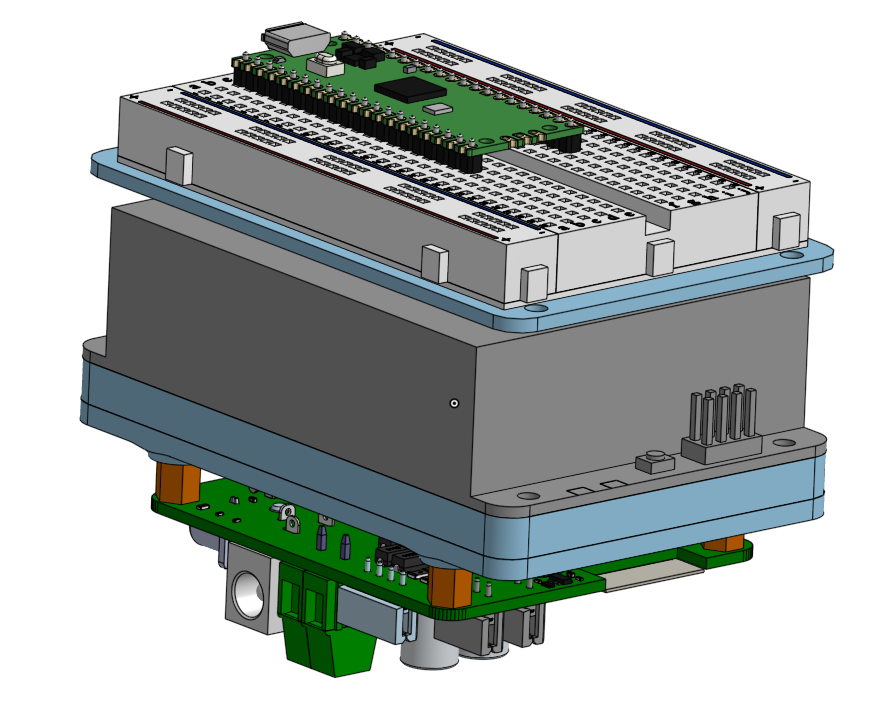
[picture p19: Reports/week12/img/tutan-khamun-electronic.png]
  

🖼️ Visual Documentation & Progress

* Pending

---

## 🔗 Documentation Links

[Tutan-Khamun Project files](../../products/tool/active/tutan-khamun/)

## 📝 To-Do List (Action Items)

### Immediate Priority

- [ ] **Hardware:**
- [ ] **Software:**
- [ ] **Manufacturing:**

### Research & Documentation

- [ ] **Research:**
- [ ] **Reports:**
- [ ] **Maintenance:** Update README with latest links and media.

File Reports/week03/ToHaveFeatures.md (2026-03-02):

Must to have features:
- Operational
- Fully automated enagage disangage.
- Seamless electrical connection.
- Easy to remove manually in case of emergency.
- Manuel and hard coded control of the gripper
- Finish before Incomplete
- Two or three gripper design.

Good to have features:
- Reliable in terms of end effector postion in multiple operations.
- Camera and Image Processing integration
- Pressure sensing
- Remote gripper controller with remote
- Autonomus control of the gripper with image processing
- Adding grippers to simulation
- Performing automated demonstration tasks

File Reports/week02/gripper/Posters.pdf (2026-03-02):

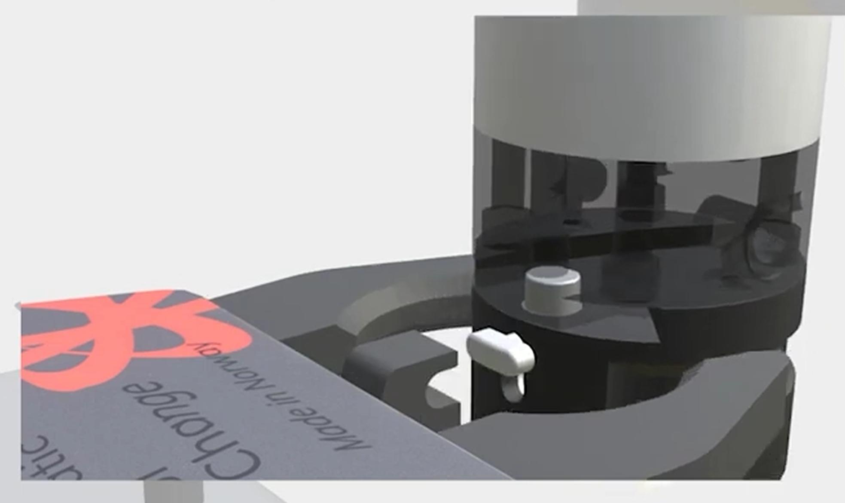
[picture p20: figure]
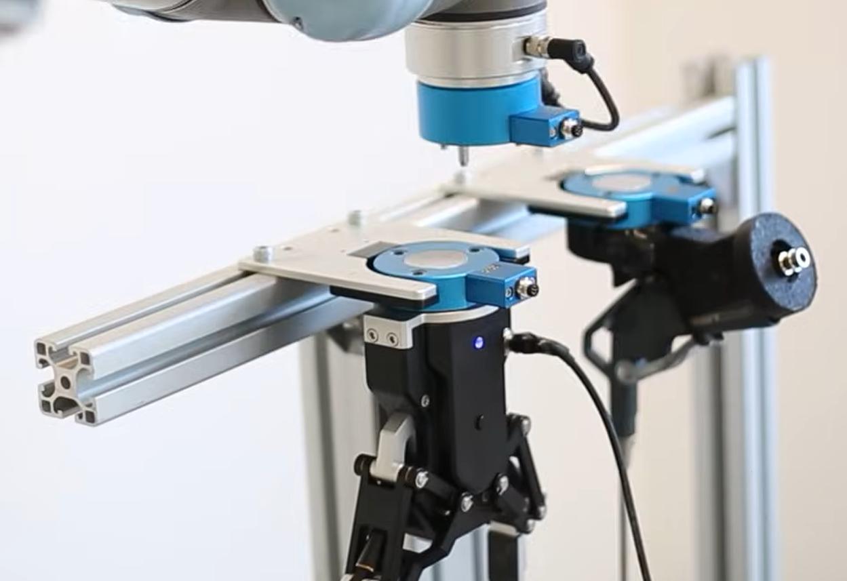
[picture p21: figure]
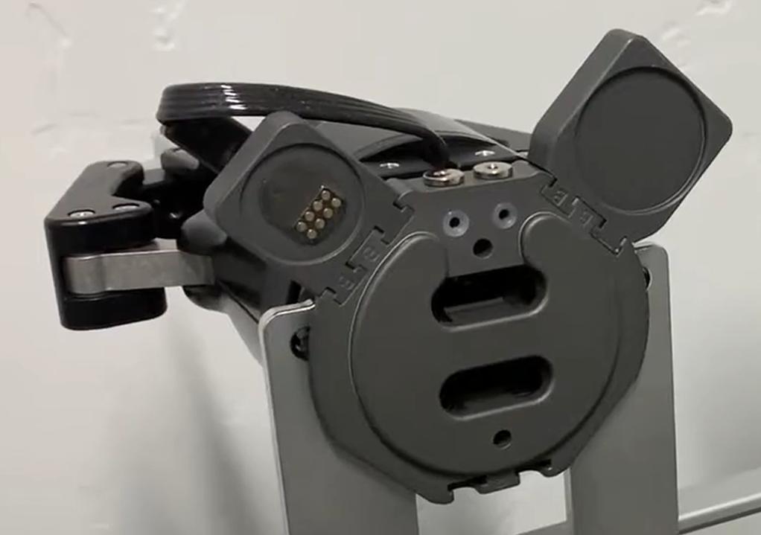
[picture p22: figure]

RESEARCH POSTER PRESENTATION DESIGN © 2022
www.PosterPresentations.com

# Objective: Design and manufactrure a reliable tool changer for robot arms with the following

properties,

# - Fully Automatic - Manual Operation if Desired * - Connects Arm and End Effector Electronically - Robust to Positional Errors - Resistant to Wear & Plastic Deformation

# Automatic Tool Change System

# Objective: Design and manufacture 2-3 end

effectors with unique functionalities and purposes.

# Some potential end effectors could be:

# A Library of End Effectors

# - Robot arm path simulation - End effector simulation * - Hardcoded serial tasks / manual operation - Automated simpler tasks * (potentially with overhead or tool mounted cameras)

# Testing/Demonstration

## References

[1] https://www.youtube.com/watch?v=DKogq75gqLg&list=PLPCmeat3ZauMB9G-j1zMtYtTFtzrOmsXM&index=10
[2] https://www.youtube.com/watch?v=B2dpcNf5LFg&list=PLPCmeat3ZauMB9G-j1zMtYtTFtzrOmsXM&index=10
[3] https://www.youtube.com/watch?v=IWDu6bApWZE&list=PLPCmeat3ZauMB9G-j1zMtYtTFtzrOmsXM&index=12 (https://www.youtube.com/watch?v=IWDu6bApWZE&list=PLPCmeat3ZauMB9G-j1zMtYtTFtzrOmsXM&index=12)
[4] https://www.youtube.com/watch?v=3M4gb9KVHWo&list=PLPCmeat3ZauMB9G-j1zMtYtTFtzrOmsXM&index=7 (https://www.youtube.com/watch?v=3M4gb9KVHWo&list=PLPCmeat3ZauMB9G-j1zMtYtTFtzrOmsXM&index=7)
[5] Craftsman Auto Buffer Polisher
[6] Lee, Dongmyoung & Chen, Wei & Chen, Xiaoshuai & Rojas, Nicolás. (2024). G.O.G: A Versatile Gripper-On-Gripper Design for Bimanual Cloth Manipulation with a Single Robotic Arm. IEEE Robotics and Automation Letters. PP. 1-8. 10.1109/LRA.2024.3357028.
{7] W. Xu, H. Zhang, H. Yuan and B. Liang, "A Compliant Adaptive Gripper and Its Intrinsic Force Sensing Method," in IEEE Transactions on Robotics, vol. 37, no. 5, pp. 1584-1603, Oct. 2021, doi: 10.1109/TRO.2021.3060971.
[8] Lee, D., Chen, W., Chen, X., & Rojas, N. (2024). Gog: A versatile gripper-on-gripper design for bimanual cloth manipulation with a single robotic arm. IEEE Robotics and Automation Letters, 9(3), 2415-2422.
[9] https://tr.pinterest.com/pin/140806233672011/

## Abdullah Naci Bodur, Ahmet Deniz Eröz, Buğra Çınaroğlu, Ogan Altuğ Okutan

# Automatic Tool Change System for Uniquely Functional End Effectors for Robot Arms

# Little Daisies MKII

# Cardboard Model Maker - Suction Holder - Glue/Pritt Holder - Cutter

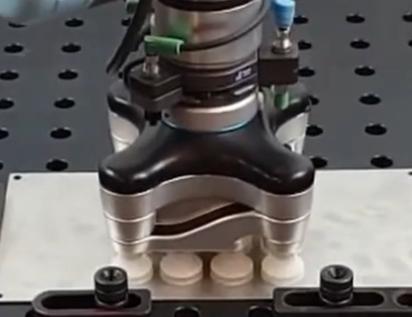
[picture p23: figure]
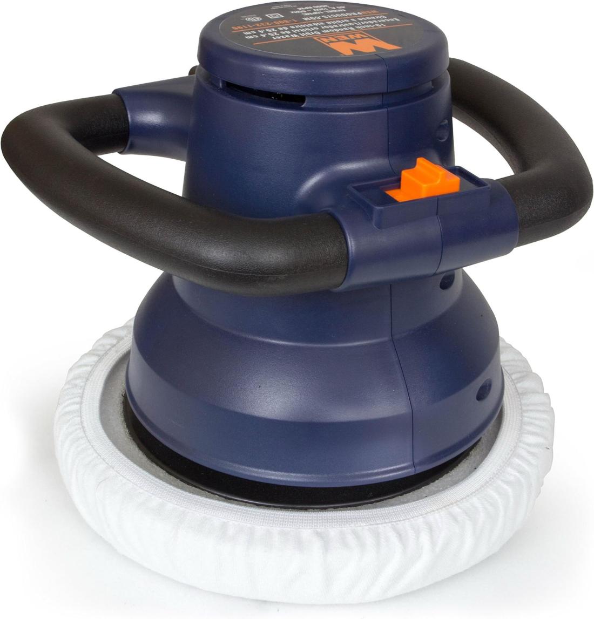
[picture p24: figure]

# Table Tidyer - Compliant Gripper - Table Cleaner - Cloth Holder *

[1]

[2]


[3]

[4]

[5]

[8]

[9]

* Project design specifications/requirements are subject to change and are here as means of suggestions/ideas


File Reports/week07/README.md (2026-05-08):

# Weekly Report: LittleDaisiesMKII - Week 7

**Date Range:** March 24 - March 30, 2026

## 📊 Team Performance & Scoring

*Evaluation of specific tasks and deliverables based on project requirements.*

| Deliverable / Metric | Score | Notes |
| :--- | :--- | :--- |
| Start controlling the arm | 7/10 | Progress made on initial control |
| Finalize passive locking requirements/drafts | 9/10 | Requirements and drafts near completion |
| Conduct decision matrix for drafts | 9/10 | Matrix analysis performed |
| Toolbox requirements / Active locking ideas  | 9/10 | Path determined based on matrix results |
| Manufacture Zen tool sieve | 2/10 | Limited progress on manufacturing |
| **Total Score** | **36/50** | **Avg: 7.2/10** |

---

## 📝 To-Do List (Action Items)

### Immediate Priority

- [ ] **Hardware:** Complete the manufacturing of the Zen tool sieve.
- [ ] **Design:** Start generating toolbox ideas now that requirements are set.
- [ ] **Manufacturing:** Move forward with the manufacture of the full set of Zen tools.
- [ ] **Control:** Refine arm control parameters.

### Research & Documentation

- [ ] **Strategic:** Finalize the toolbox requirements based on the decision matrix outcome.
- [ ] **Reports:** Document the justification for design choices derived from the numeric proofs.


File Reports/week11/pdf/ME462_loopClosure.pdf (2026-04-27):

# ME462 Loop Closure Kinematic Analysis

### Little Daisies

### April 2026

## Kinematic Model


Figure 1: Kinematic system.

The loop closure equation is

OA⃗ + AB⃗ + BC⃗ + CD⃗ + DO⃗ = 0

or in complex form,

cx + a1e

iθ1 + a2e

iθ2 − a3e

iθ3 − cyi = 0

Separating into real and imaginary parts:

cx + a1 cos θ1 + a2 cos θ2 − a3 cos θ3 = 0 | (1)
a1 sin θ1 + a2 sin θ2 − a3 sin θ3 − cy = 0 | (2)

## Solution for Input θ1

Define

C1 = cx + a1 cos θ1

C2 = a1 sin θ1 − cy

Then (1) and (2) become

a3 cos θ3 = C1 + a2 cos θ2

a3 sin θ3 = C2 + a2 sin θ2

Squaring and adding,

a

2
3 = (C1 + a2 cos θ2)

2 + (C2 + a2 sin θ2)

2

a

2
3 = C

2
1 + C

2
2 + a

2
2 + 2a2(C1 cos θ2 + C2 sin θ2)

Therefore,

C1 cos θ2 + C2 sin θ2 =

a

2
3 − a

2
2 − C

2
1 − C

2
2
2a2

Define

d =

q
C²

1 + C²
2

ϕ = atan2(C2, C1)

Since

C1 = d cos ϕ, C2 = d sin ϕ

we obtain

d cos(θ2 − ϕ) = a

| 2 3 − a
| 2 2 − d
| 2
| 2a2

Hence,

θ2 = ϕ ± cos⁻¹

a

2
3 − a

2
2 − d

2
2a2d

After finding θ2, θ3 is found from

θ3 = atan2 (C2 + a2 sin θ2, C1 + a2 cos θ2)

## Solution for Input θ3

For a given input θ3, define

K1 = a3 cos θ3 − cx

K2 = cy + a3 sin θ3

Then (1) and (2) become

a1 cos θ1 + a2 cos θ2 = K1

a1 sin θ1 + a2 sin θ2 = K2

Rearranging,

a1 cos θ1 = K1 − a2 cos θ2

a1 sin θ1 = K2 − a2 sin θ2

Squaring and adding,

a

2
1 = (K1 − a2 cos θ2)

2 + (K2 − a2 sin θ2)

2

a

2

1 = K²

1 + K²
2 + a

2
2 − 2a2(K1 cos θ2 + K2 sin θ2)

Therefore,

K1 cos θ2 + K2 sin θ2 =

K²

1 + K²
2 + a

2
2 − a

2
1
2a2

Define

s =

q
K²

1 + K²
2

ψ = atan2(K2, K1)

Since

K1 = s cos ψ, K2 = s sin ψ

we obtain

s cos(θ2 − ψ) = s

| 2 + a
| 2 2 − a
| 2
| 1 2a2

Hence,

θ2 = ψ ± cos⁻¹

s

2 + a

2
2 − a

2
1
2a2s

After finding θ2, θ1 is found from

θ1 = atan2 (K2 − a2 sin θ2, K1 − a2 cos θ2)

## Distance Calculation


Figure 2: Distance definition for the orange part.

The position of the orange point is written as

e1 + cyi + a3e

iθ3 + d1e

i(γ+θ2−π) = Lx + Lyi

Separating into real and imaginary parts gives

Lx = e1 + a3 cos θ3 + d1 cos(γ + θ2 − π)

Ly = cy + a3 sin θ3 + d1 sin(γ + θ2 − π)

Therefore, the distance is

L =

q
L²

x + L²
y

## Final Form

For input θ1:

C1 = cx + a1 cos θ1

C2 = a1 sin θ1 − cy

d =

q
C²

1 + C²
2

ϕ = atan2(C2, C1)

θ2 = ϕ ± cos⁻¹

a

2
3 − a

2
2 − d

2
2a2d

θ3 = atan2 (C2 + a2 sin θ2, C1 + a2 cos θ2)

For input θ3:

K1 = a3 cos θ3 − cx

K2 = cy + a3 sin θ3

s =

q
K²

1 + K²
2

ψ = atan2(K2, K1)

θ2 = ψ ± cos⁻¹

s

2 + a

2
2 − a

2
1
2a2s

θ1 = atan2 (K2 − a2 sin θ2, K1 − a2 cos θ2)

The feasibility conditions are

|a3 − a2| ≤ d ≤ a3 + a2

for input θ1, and

|a1 − a2| ≤ s ≤ a1 + a2

for input θ3.

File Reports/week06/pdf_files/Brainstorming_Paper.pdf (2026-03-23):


Group: | FUNCTION :
Student Name: | Student Name: | Student Name: | Student Name:

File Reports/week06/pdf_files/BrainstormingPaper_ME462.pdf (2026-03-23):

Group: | FUNCTION :
Student Name: | Student Name: | Student Name: | Student Name:


Group: | FUNCTION :
Student Name: | Student Name: | Student Name: | Student Name:





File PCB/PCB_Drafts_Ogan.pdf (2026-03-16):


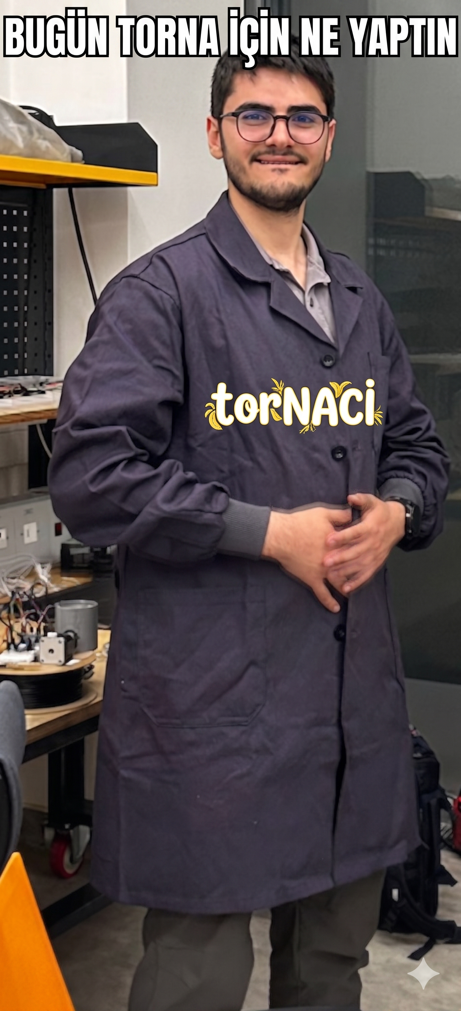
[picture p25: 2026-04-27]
Reports/week11/img/tornaci1.png

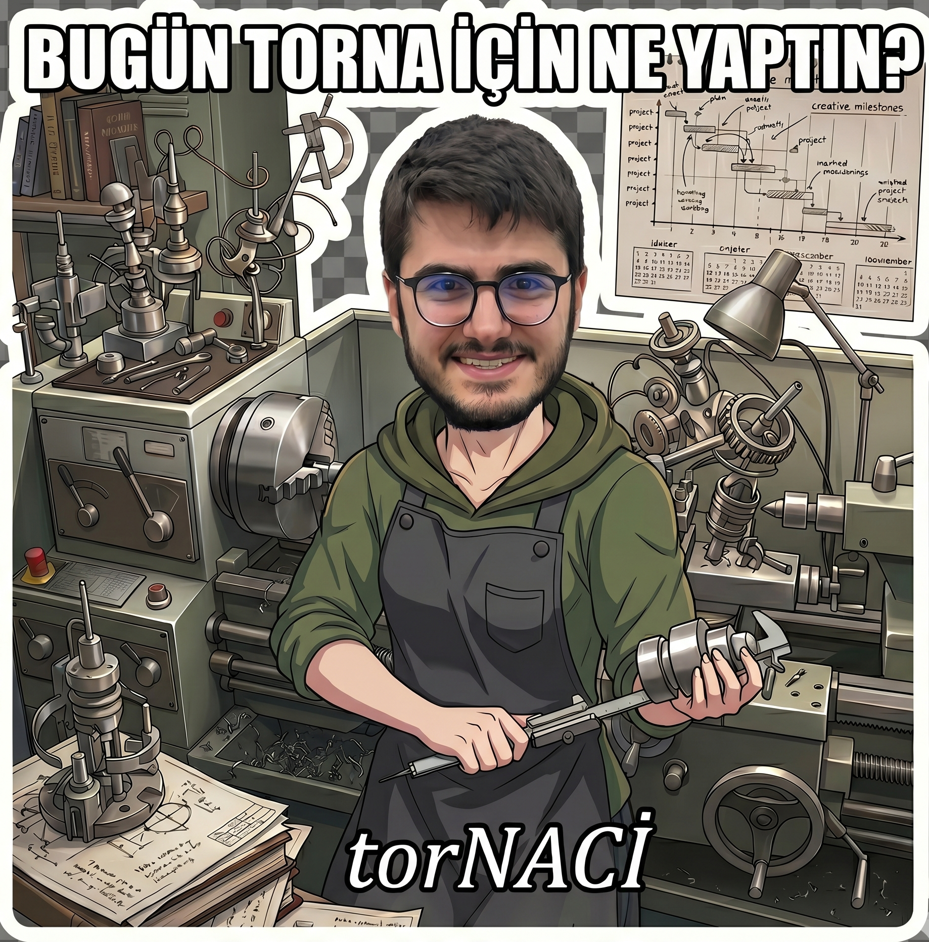
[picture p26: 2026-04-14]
Reports/week09/img/tornaci3.png

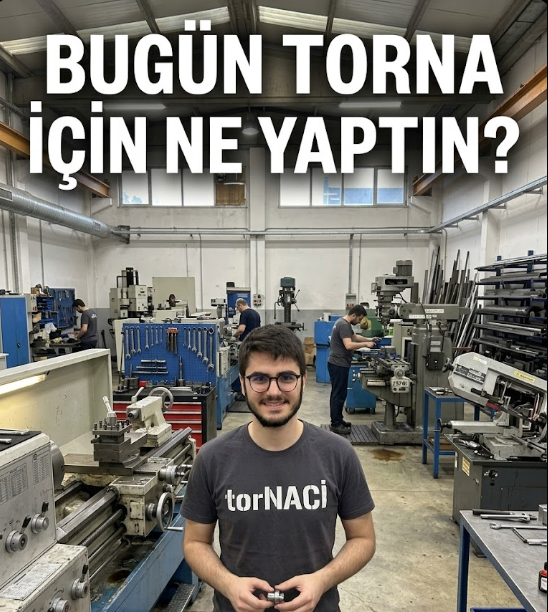
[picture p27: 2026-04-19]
Reports/week10/img/tornaci.png

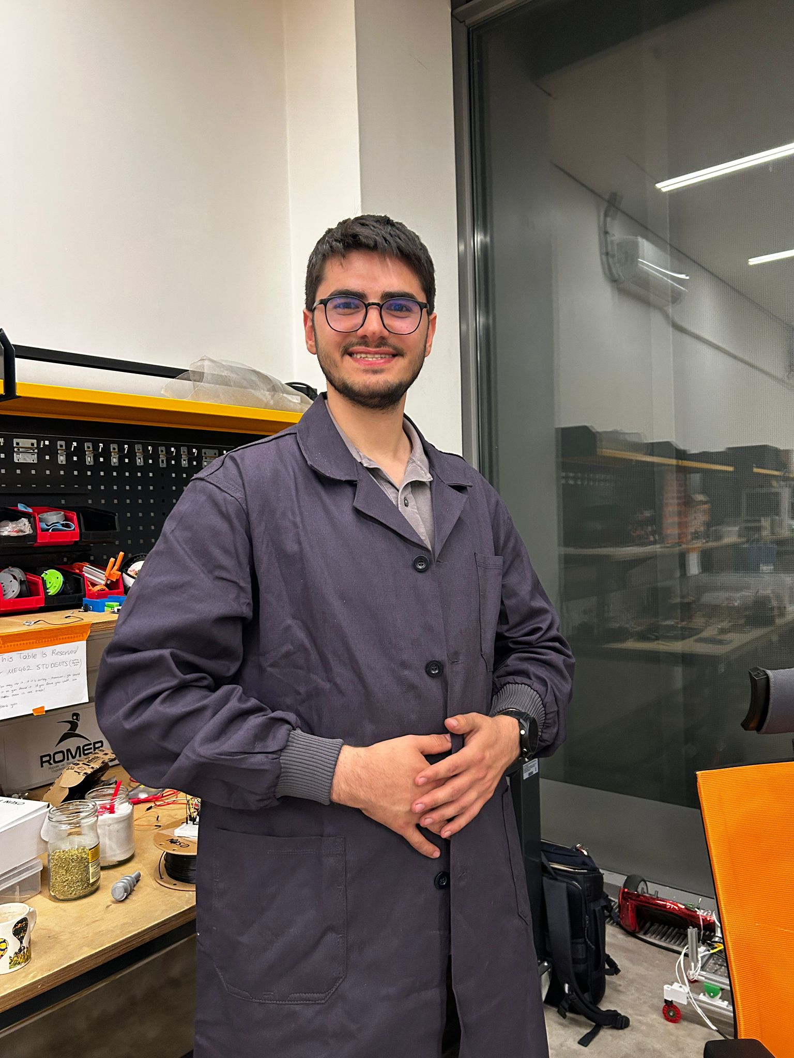
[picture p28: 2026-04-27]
Reports/week11/img/naci2.jpeg

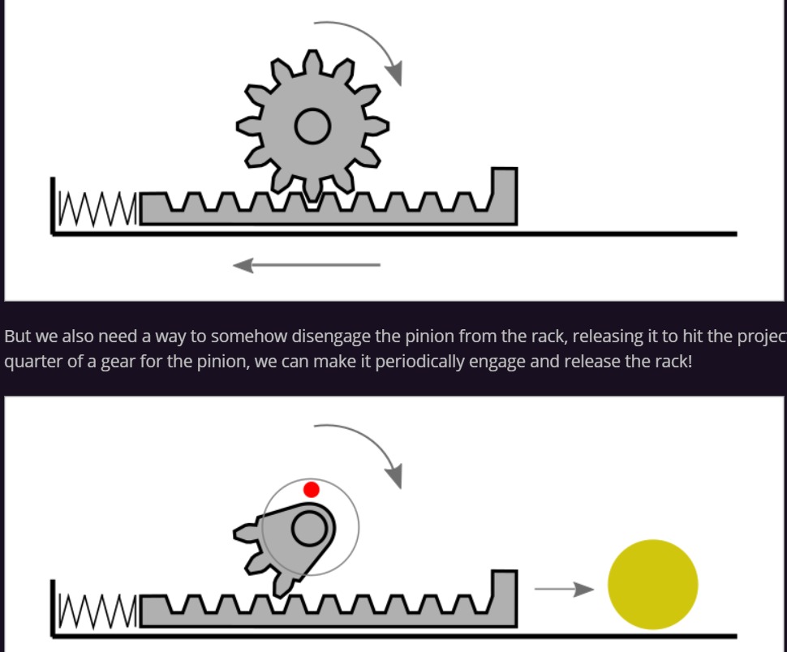
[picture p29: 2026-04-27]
Reports/week11/img/shooting_mechanism.jpeg

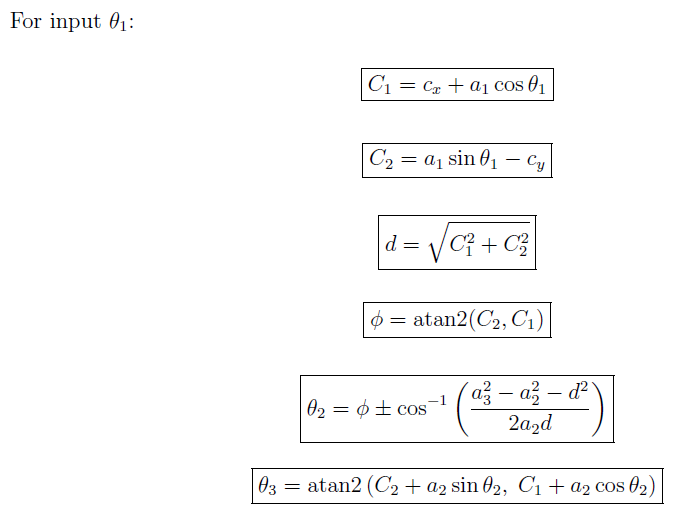
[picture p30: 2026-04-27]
Reports/week11/img/derivation1.png

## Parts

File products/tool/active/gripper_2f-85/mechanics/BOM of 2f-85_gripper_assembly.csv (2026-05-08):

Item | Quantity | Name
1 | 2 | 2f-85_finger
2 | 2 | 2f-85_finger_actuator
3 | 2 | 2f-85_finger_rotator
4 | 2 | 2f-85_finger_supporter
5 | 2 | 2f-85_finger_tips
6 | 1 | 2f-85_base_3
7 | 1 | 2f-85_base_2
8 | 1 | 2f-85_base_1
9 | 4 | M2X8
10 | 2 | Metal Servo Arm
11 | 2 | DS3225MG 25KG
12 | 2 | DS3225MG 25KG
13 | 1 | servo_holder

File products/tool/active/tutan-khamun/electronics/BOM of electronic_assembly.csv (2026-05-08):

Item | Quantity | Name
1 | 1 | Raspberry Pi 4
2 | 1 | Raspberry Pi Pico
3 | 1 | 12V UPS
4 | 1 | Mini Breadboard
5 | 4 | hex_m3_l6_bn

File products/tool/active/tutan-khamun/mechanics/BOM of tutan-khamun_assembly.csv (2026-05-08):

Item | Quantity | Name
1 | 1 | base_link_holder
2 | 2 | 金属舵盘（从动） v2
3 | 2 | 金属舵盘（驱动） v2
4 | 2 | GE_27
5 | 2 | PCB-CHAZUO_92
6 | 2 | MOTOR-1723_3
7 | 2 | XG-ZIJI_16
8 | 2 | SG-ZIJI_15
9 | 2 | ZK_122
10 | 2 | actuator
11 | 2 | rotator
12 | 2 | supporter
13 | 2 | finger_holder
14 | 6 | Hex socket head cap screw M5x0.80 x 50 x 22
15 | 16 | Hex socket head cap screw M2.5x0.45 x 8
16 | 16 | Chamfered plain washer normal M2.5
17 | 22 | Chamfered plain washer normal M5
18 | 6 | Prevailing torque nut M5x0.80
19 | 2 | Socket button head screw M5x0.8 x 40
20 | 2 | Socket button head screw M5x0.8 x 45

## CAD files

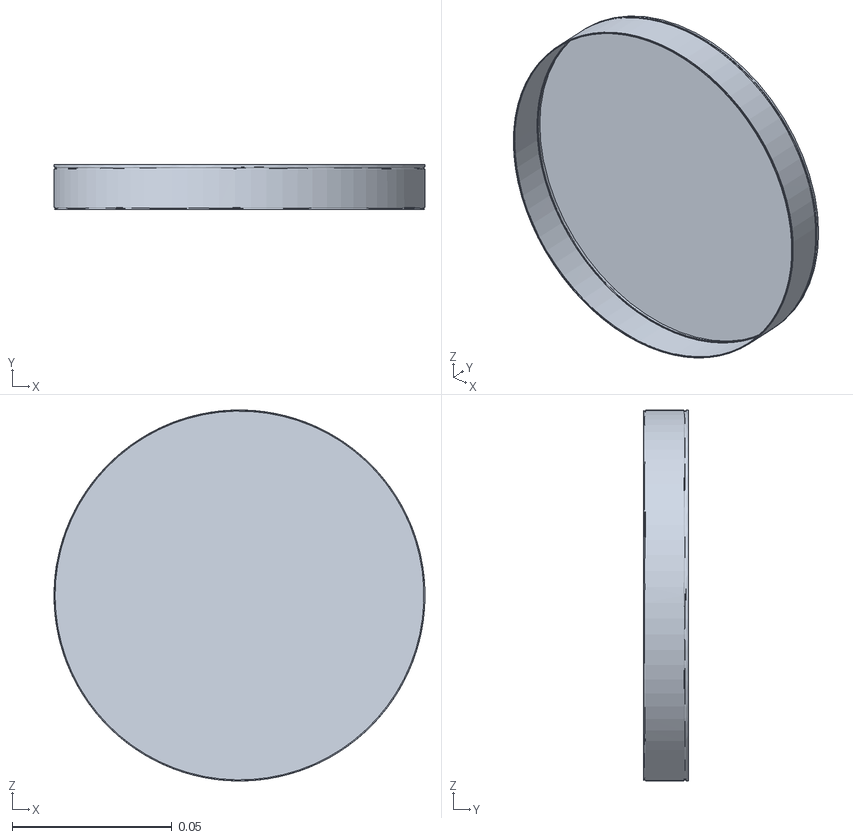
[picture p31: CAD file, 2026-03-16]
MujocoSim/assets/shoulder_1.obj
0.116 x 0.0142 x 0.116

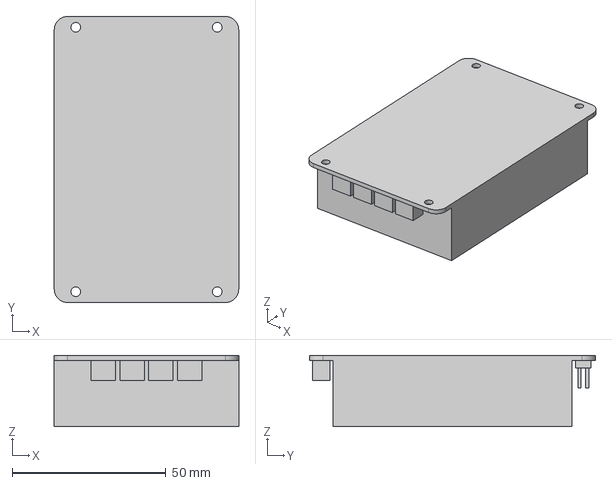
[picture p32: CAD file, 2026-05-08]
products/tool/active/gripper_2f-85/electronics/imported_cad_files/UPS_Module_3Sstep/UPS_Module_3S.step
60.0 x 93.0 x 23.1 mm

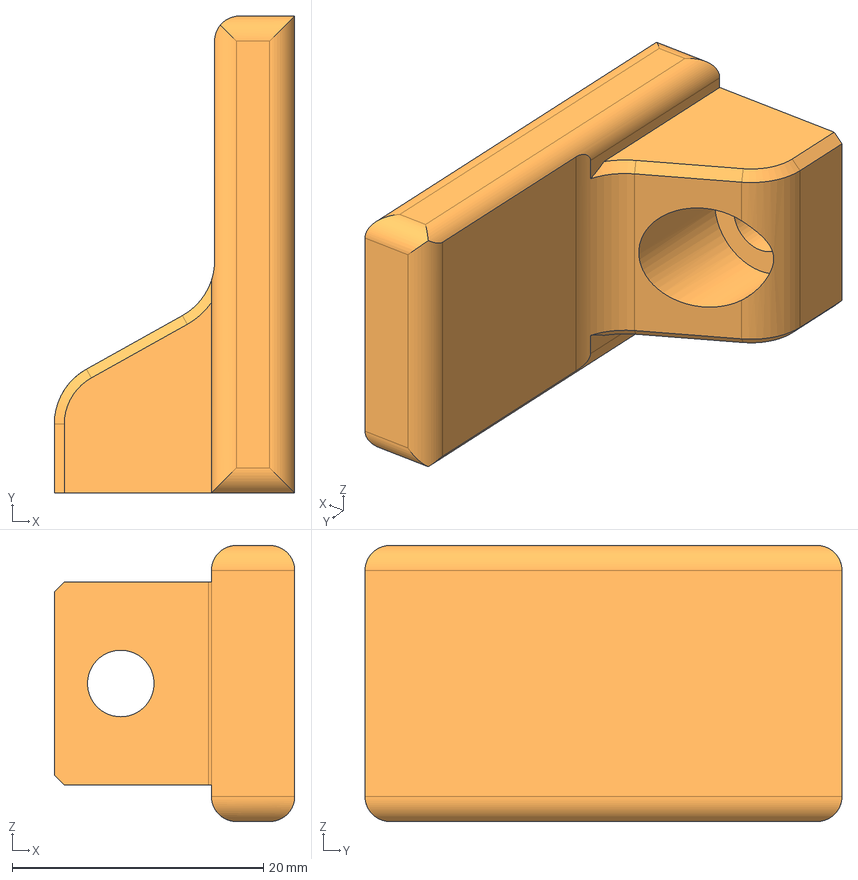
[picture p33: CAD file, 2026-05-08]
products/tool/active/gripper_2f-85/mechanics/3d_parts/2f-85_finger_tips - 2f-85_finger_tips.step
19.2 x 38.0 x 22.0 mm

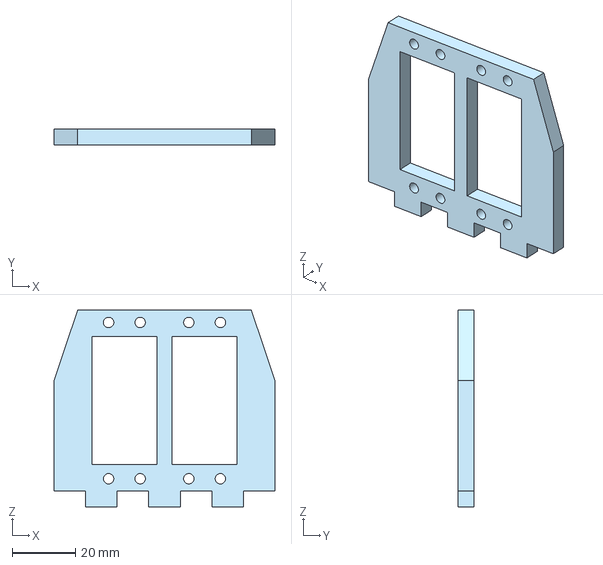
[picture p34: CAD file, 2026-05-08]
products/tool/active/gripper_2f-85/mechanics/plexy/servo_holder - servo_holder.step
70.0 x 5.00 x 62.3 mm

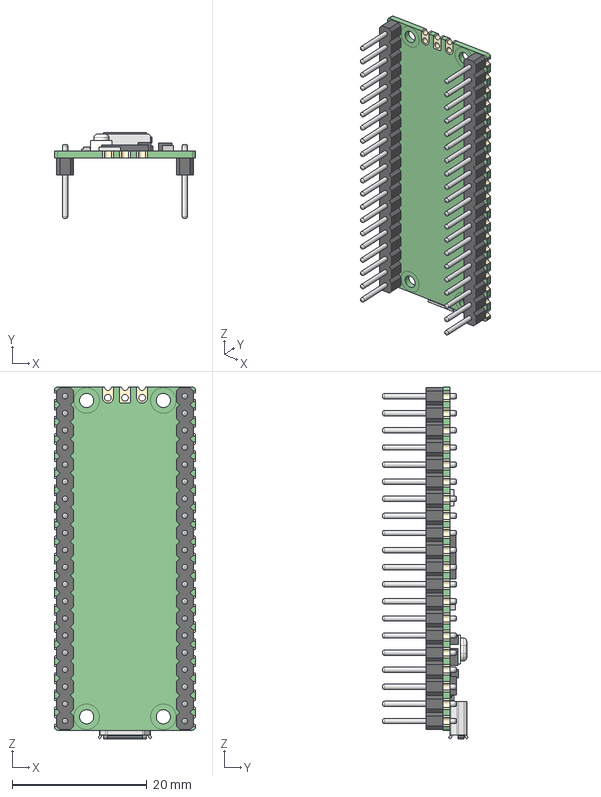
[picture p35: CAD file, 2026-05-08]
products/tool/active/tutan-khamun/electronics/imported_cad_files/raspberry-pi-pico-w-pins-1.snapshot.4/PICO_PinsDown.STEP
21.0 x 12.7 x 52.3 mm
PICO_REF_BOARD.STEP
PICO_REF_USB.STEP
PICO_REF_SWITCH.STEP
PICO_REF_MICROCONTROLLER.STEP
PICO_REF_LED.STEP
PICO_REF_ONSEMI.STEP
PICO_BOURNS.STEP
PICO_MURATA.STEP x 2
PICO_RICHTEK.STEP
PICO_DIODES.STEP
PICO_AEL.STEP
PICO_PIN_HEADERS
PICO_HEADER_HOLES

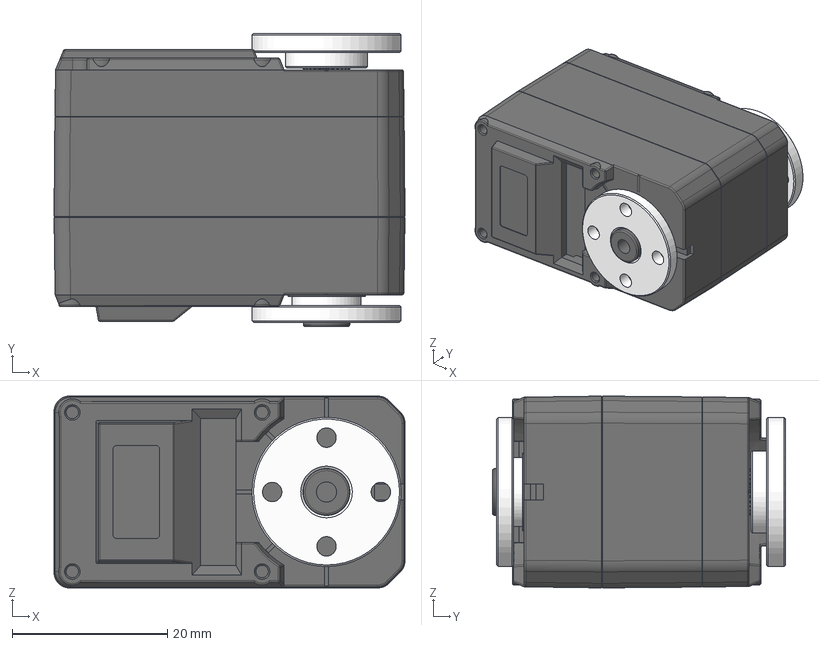
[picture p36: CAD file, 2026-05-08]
products/tool/active/tutan-khamun/electronics/imported_cad_files/st3215-1.snapshot.2/ST3215 Servo.stp
45.2 x 37.8 x 24.7 mm
ZK_122
SG-ZIJI_15
XG-ZIJI_16
MOTOR-1723_3
PCB-CHAZUO_92
GE_27
金属舵盘（驱动）
金属舵盘（从动）

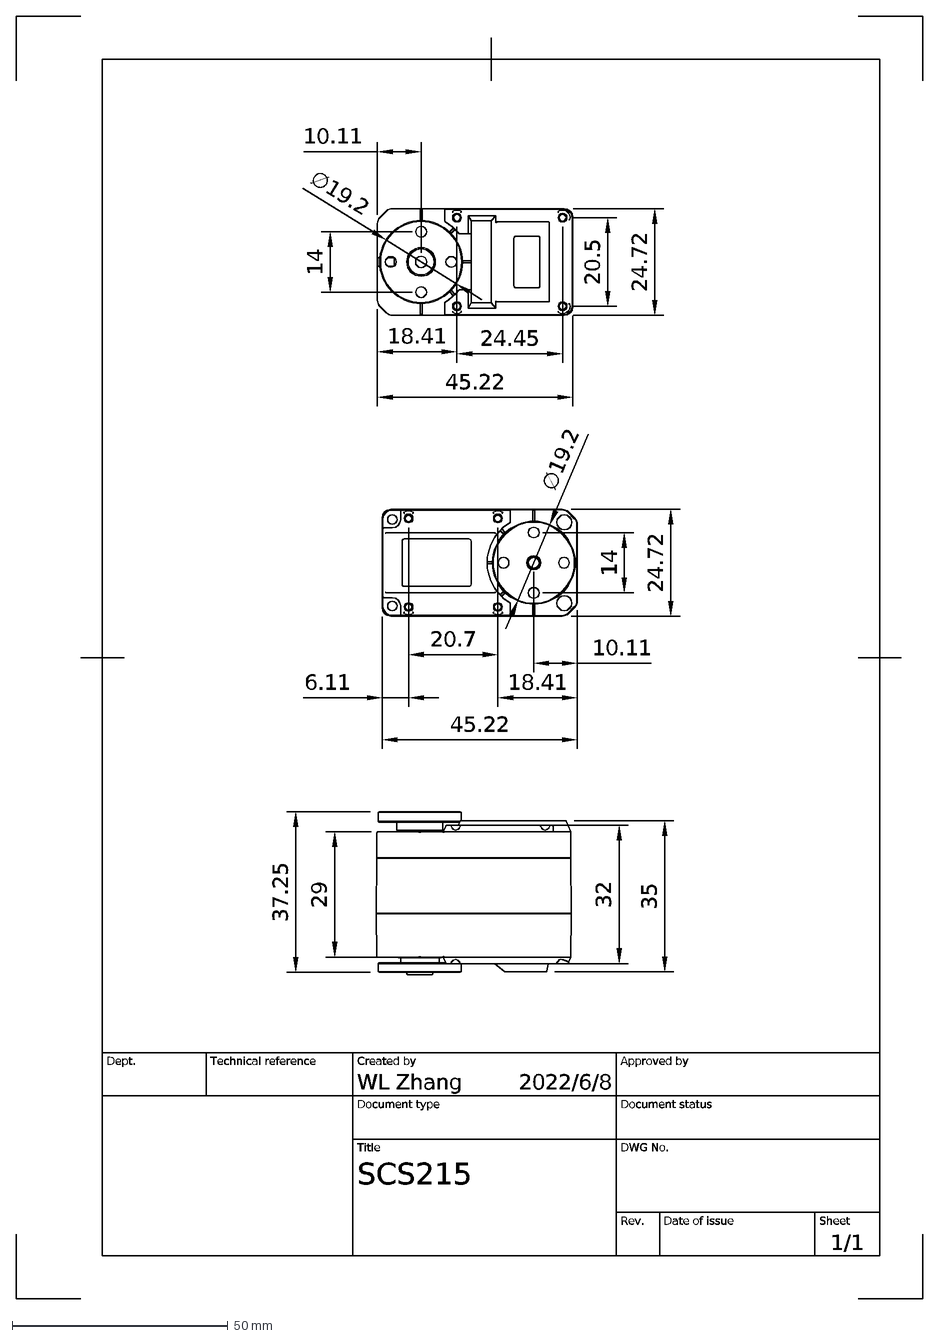
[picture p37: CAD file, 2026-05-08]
products/tool/active/tutan-khamun/electronics/imported_cad_files/ST3215-2D/ST3215.dxf
2022/6/8
1/1
SCS215
WL Zhang
Dept.
Technical reference
Created by
Approved by
Document type
Document status
Title
DWG No.
Rev.
Date of issue
Sheet
24.45
18.41
10.11
20.5
24.72
45.22
37.25
20.7
6.11
∅19.2
14
32
35
29

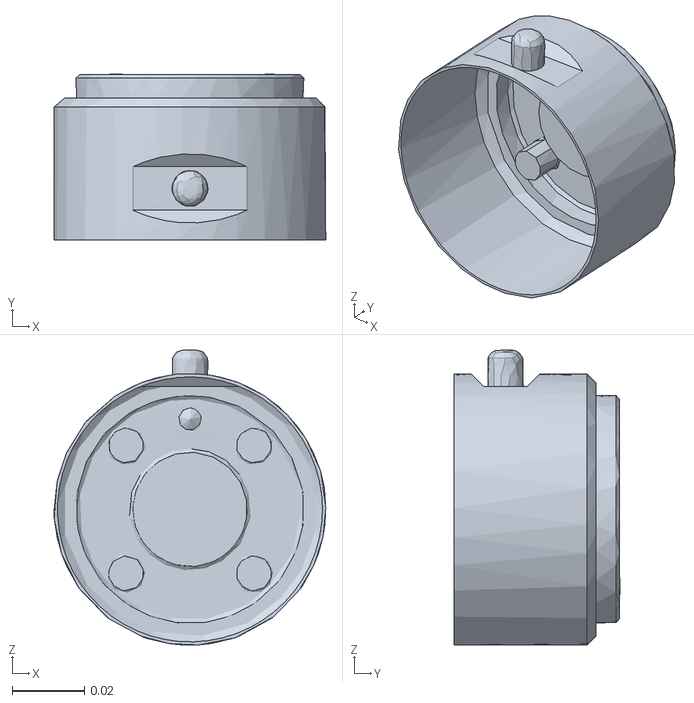
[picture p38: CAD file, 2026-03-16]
MujocoSim/assets/wrist3.obj
0.0751 x 0.0458 x 0.0816

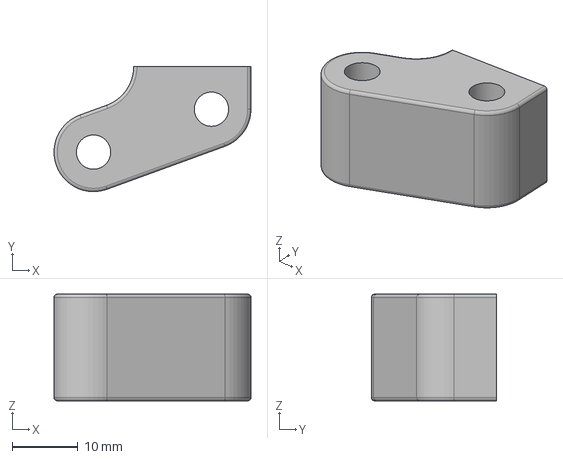
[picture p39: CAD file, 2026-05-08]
products/tool/active/gripper_2f-85/mechanics/3d_parts/2f-85_finger - 2f-85_finger.step
29.9 x 19.0 x 16.2 mm

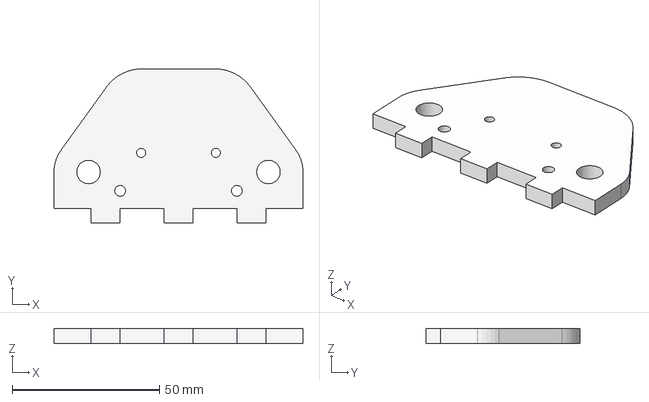
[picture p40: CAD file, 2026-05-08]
products/tool/active/gripper_2f-85/mechanics/plexy/2f-85_base - 2f-85_base_1.step
84.7 x 52.5 x 5.00 mm

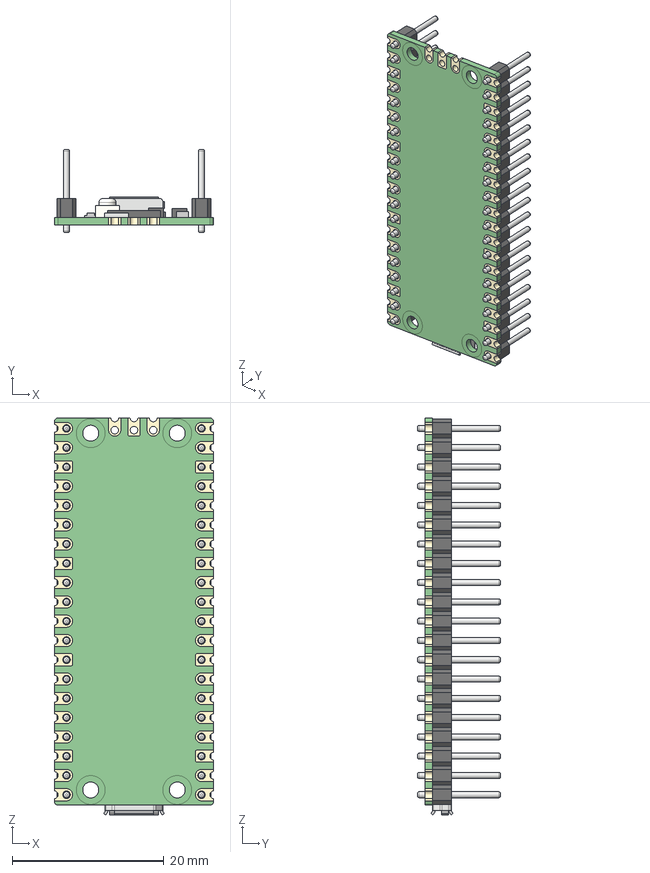
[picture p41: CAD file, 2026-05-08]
products/tool/active/tutan-khamun/electronics/imported_cad_files/raspberry-pi-pico-w-pins-1.snapshot.4/PICO_PinsUp.STEP
21.0 x 11.0 x 52.3 mm
PICO_REF_BOARD.STEP
PICO_REF_USB.STEP
PICO_REF_SWITCH.STEP
PICO_REF_MICROCONTROLLER.STEP
PICO_REF_LED.STEP
PICO_REF_ONSEMI.STEP
PICO_BOURNS.STEP
PICO_MURATA.STEP x 2
PICO_RICHTEK.STEP
PICO_DIODES.STEP
PICO_AEL.STEP
PICO_PIN_HEADERS
PICO_HEADER_HOLES

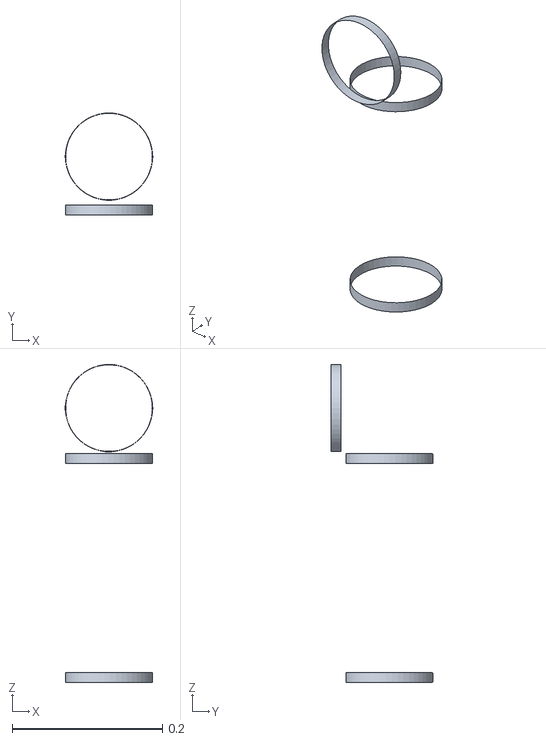
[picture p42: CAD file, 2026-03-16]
MujocoSim/assets/upperarm_1.obj
0.116 x 0.136 x 0.423

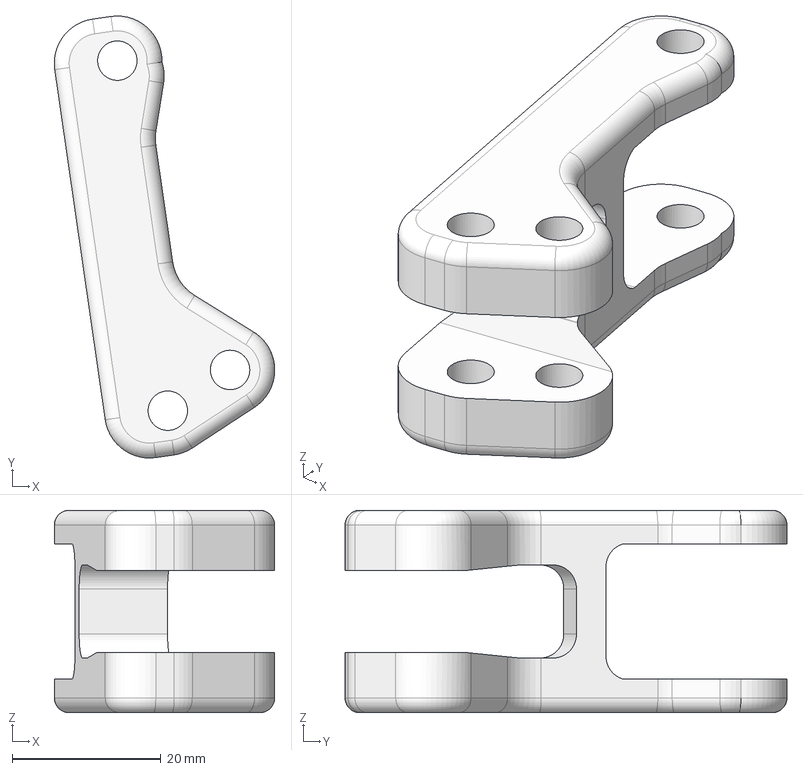
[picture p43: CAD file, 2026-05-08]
products/tool/active/gripper_2f-85/mechanics/3d_parts/2f-85_finger_supporter - 2f-85_finger_supporter.step
29.6 x 59.4 x 27.2 mm

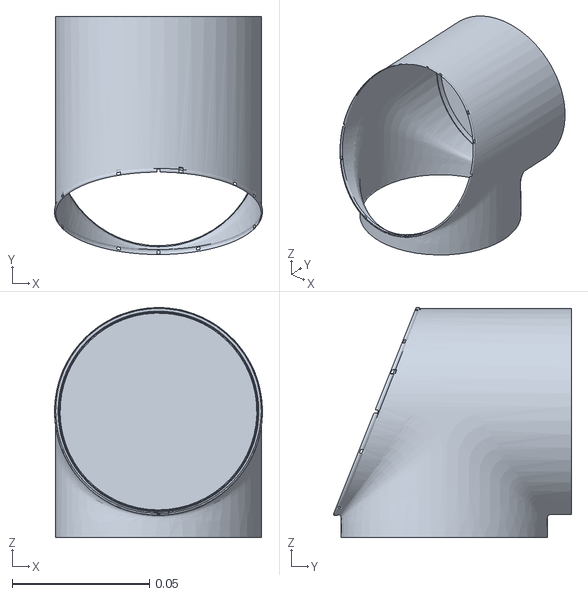
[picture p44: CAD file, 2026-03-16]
MujocoSim/assets/wrist2_2.obj
0.0757 x 0.0866 x 0.0837

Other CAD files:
products/tool/active/gripper_2f-85/mechanics/plexy/2f-85_base - 2f-85_base_2.step
products/tool/active/gripper_2f-85/mechanics/3d_parts/2f-85_finger_actuator - 2f-85_finger_actuator.step
MujocoSim/assets/wrist2_1.obj
MujocoSim/assets/base_0.obj
MujocoSim/assets/base_1.obj
MujocoSim/assets/forearm_0.obj
MujocoSim/assets/forearm_1.obj
MujocoSim/assets/forearm_2.obj
MujocoSim/assets/forearm_3.obj
MujocoSim/assets/shoulder_0.obj
MujocoSim/assets/shoulder_2.obj
MujocoSim/assets/upperarm_0.obj
MujocoSim/assets/upperarm_2.obj
MujocoSim/assets/upperarm_3.obj
MujocoSim/assets/wrist1_0.obj
MujocoSim/assets/wrist1_1.obj
MujocoSim/assets/wrist1_2.obj
MujocoSim/assets/wrist2_0.obj
products/tool/active/gripper_2f-85/mechanics/3d_parts/2f-85_finger_rotator - 2f-85_finger_rotator.step
products/tool/active/tutan-khamun/electronics/imported_cad_files/18650-li-ion-battery-5.snapshot.1/18650 Battery.STEP
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

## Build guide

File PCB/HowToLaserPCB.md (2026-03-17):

# Complete Guide for Laser-Cut PCB Manufacturing at ROMER

This report was created for the ME462 course, and it is focused on PCB production at ROMER.

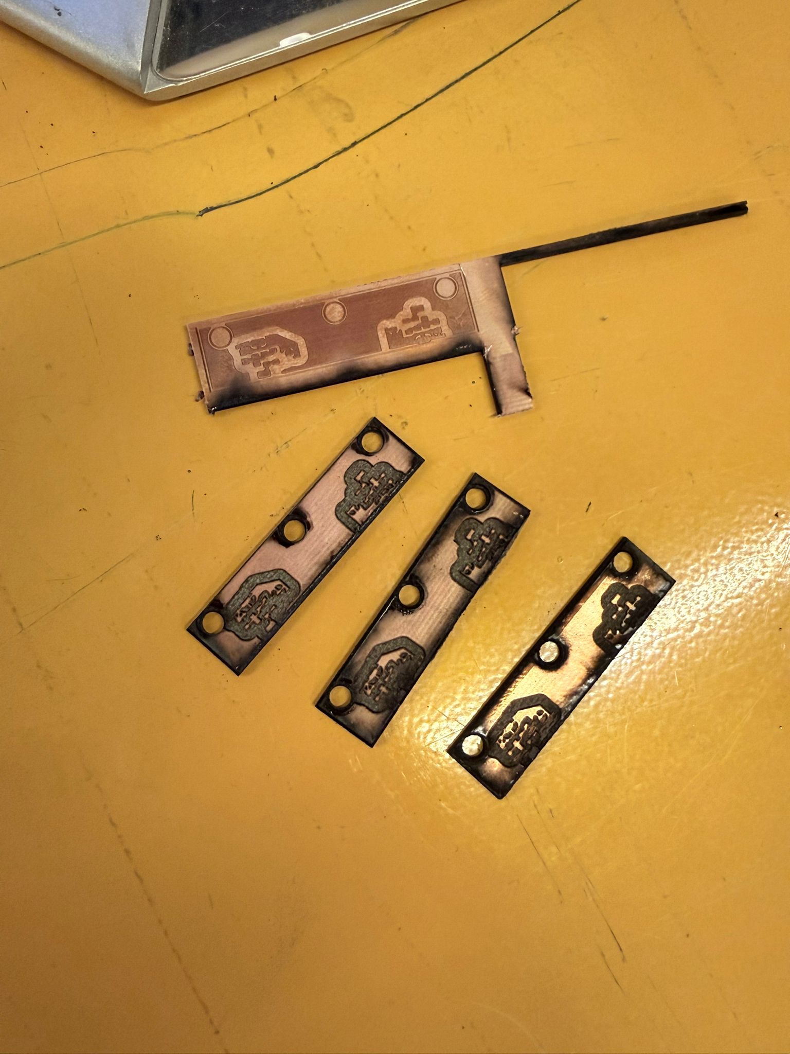
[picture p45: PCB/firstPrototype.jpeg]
First Prototype


## Step-by-Step Workflow

1. **Design**
   Create your PCB schematic and layout using any preferred PCB design software (e.g., Eagle, KiCad, or similar).
2. **Export Negatives**
   Export your completed design as negative images. This means areas where you want copper removed should be black, and regions where you want it kept should be white. Separate your export files based on the manufacturing operations: one file for engraving (removal of copper areas) and another file for cutting (defining board outlines and via holes).
3. **Use SVG and DXF Format**
   When exporting from your design software, select **SVG** (Scalable Vector Graphics) as the file export format. This ensures your design scales without loss of quality. Also, use a **DXF** (Drawing Exchange Format) file to create the boundaries for the PCB to cut.
4. **Open in Inkscape**
   Launch Inkscape and open your exported engraving SVG file.
5. **Apply Inkscape Settings**
   Perform these actions precisely in Inkscape:

   * Go to **File > Document Properties** and click on "Resize to content". Close this menu.
   * Click anywhere on your design and press `Ctrl+A` to select all elements.
   * From the **Path** menu, select **Stroke to Path** to convert any outlines into shapes. This is a critical step for laser engraving.
   * Immediately after, from the same **Path** menu, select **Union** to combine all converted shapes.
6. **Re-export SVG**
   Export the modified file again as an SVG to save these updated vector paths.
7. **Use xTool Software**
   Switch over to the native control software for your xTool F2 Ultra machine.
8. **Create Machine Layers**
   Within the laser software, create distinct layers. Place the geometry for engraving on one layer and the cutting geometry on another. This allows you to assign different laser parameters to each process.
9. **Import Engraving Data**
   Import the geometry you defined in Inkscape for areas to be engraved onto its corresponding layer.
10. **Engraving Parameters**
    For the engraving layer, set the operation type to "Engrave" and use these initial parameters:

    * **Laser Type:** MOPA IR (Infrared)
    * **Pulse Width:** 60
    * **Passes:** 25
    * **Power:** 80%
11. **Monitor Engraving**
    Closely observe the entire engraving process. You will notice that the laser beam typically glows green as it removes copper. **The moment the light shifts from green to a standard orange-red colour, stop the operation immediately.** This change in colour indicates that the laser has removed all copper and is beginning to etch the underlying laminate (FR4), which could quickly burn through.
12. **Cutting Setup**
    Move on to setting up the cutting operations. For clear board edges and via/through-hole outlines, it can be very practical to export your cutting layout as a DXF file and import it directly at this stage.
13. **Cutting Parameters**
    Assign the external board outline and any internal cutout geometry to your cutting layer. Select the "Cut" operation and use these parameters:

    * **Laser Type:** MOPA IR
    * **Pulse Width:** 60
    * **Passes:** 8
    * **Power:** 60%

    Execute the cutting operation.

---

## Important Process Notes & Best Practices

* **Substrate Durability:** Even though FR4 laminate offers significantly better resistance and durability than FR1 during laser processes, it is important to remember that it is still not indestructible. Excessive exposure from the laser can and will leave burnt edges and surface charring.
* **Tip for Cleaner Cuts:** To minimise burning, a more advanced workflow involves performing all your cutting passes *before* engraving. Use a custom-made jig (easily designed and 3D printed) that matches your board shape and external features. This jig can then be used to precisely flip the board over, allowing you to perform engraving and creation on the backside while minimising burn damage on the main front face.

---

## Guide for Creating DIY PCB Vias

A via is a plating or mechanical conductor that creates an electrical connection between different copper layers on a multi-layer printed circuit board (PCB). For single and double-sided PCBs, creating reliable DIY vias is crucial for signal integrity. Here are common methods for making vias at home, followed by a step-by-step process using the simplest technique:

### Common DIY Via Methods

* **Rivet Vias:** This is the most reliable and aesthetically pleasing DIY method. It involves inserting tiny brass or copper rivets (via pins) into drilled holes and then mechanically pressing or soldering them flush on both sides. This method offers excellent conductivity and high mechanical strength.
* **Wire Spike Vias:** This is the simplest and most accessible method. It requires inserting a small piece of thin wire (like a component lead or thin copper wire) through the drilled via hole and soldering it on both the top and bottom copper layers.

### Step-by-Step Guide for Creating Simple Wire Vias

1. **Drill via holes:** After your PCB is cut and etched, use a very fine drill bit (0.5 mm - 1.0 mm diameter, matching your via pad size) to drill completely through the pads on your board where a via connection is required.
2. **Insert wire:** Cut a short segment of thin copper wire (solid-core wire works best) and insert it completely through the drilled via hole.
3. **Solder the first side:** On the top copper layer, apply solder to the pad and wire lead. Solder the wire flush with the surface of the copper pad.
4. **Solder the second side:** Flip the PCB over and apply solder to the corresponding pad on the bottom copper layer, ensuring you make a solid connection with the same wire lead.
5. **Trim excess wire:** Use fine side cutters (like flush cutters) to snip any remaining wire spikes flush with the top and bottom copper pads.
6. **Verify electrical connection:** Use a digital multimeter in continuity or resistance mode to check the connection between the top and bottom pads of each via. A reading near zero ohms confirms a solid, low-resistance electrical pathway.

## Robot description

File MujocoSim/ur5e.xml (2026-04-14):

<mujoco model="ur5e">
  <compiler angle="radian" meshdir="assets" autolimits="true"/>

  <option integrator="implicitfast" timestep="0.002"/>

  <default>
    <default class="ur5e">
      <material specular="0.5" shininess="0.25"/>
      <joint axis="0 1 0" range="-6.28319 6.28319" armature="0.1"/>
      <general gaintype="fixed" biastype="affine" ctrlrange="-6.2831 6.2831" gainprm="2000" biasprm="0 -2000 -400" forcerange="-150 150"/>
      <default class="size3">
        <default class="size3_limited">
          <joint range="-3.1415 3.1415"/>
          <general ctrlrange="-3.1415 3.1415"/>
        </default>
      </default>
      <default class="size1">
        <general gainprm="500" biasprm="0 -500 -100" forcerange="-28 28"/>
      </default>
      <default class="visual">
        <geom type="mesh" contype="0" conaffinity="0" group="2"/>
      </default>
      <default class="collision">
        <geom type="capsule" group="3"/>
        <default class="eef_collision">
          <geom type="cylinder"/>
        </default>
      </default>
      <site size="0.001" rgba="0.5 0.5 0.5 0.3" group="4"/>
    </default>
  </default>

  <asset>
    <material class="ur5e" name="black" rgba="0.033 0.033 0.033 1"/>
    <material class="ur5e" name="jointgray" rgba="0.278 0.278 0.278 1"/>
    <material class="ur5e" name="linkgray" rgba="0.82 0.82 0.82 1"/>
    <material class="ur5e" name="urblue" rgba="0.49 0.678 0.8 1"/>

    <mesh file="base_0.obj"/>
    <mesh file="base_1.obj"/>
    <mesh file="shoulder_0.obj"/>
    <mesh file="shoulder_1.obj"/>
    <mesh file="shoulder_2.obj"/>
    <mesh file="upperarm_0.obj"/>
    <mesh file="upperarm_1.obj"/>
    <mesh file="upperarm_2.obj"/>
    <mesh file="upperarm_3.obj"/>
    <mesh file="forearm_0.obj"/>
    <mesh file="forearm_1.obj"/>
    <mesh file="forearm_2.obj"/>
    <mesh file="forearm_3.obj"/>
    <mesh file="wrist1_0.obj"/>
    <mesh file="wrist1_1.obj"/>
    <mesh file="wrist1_2.obj"/>
    <mesh file="wrist2_0.obj"/>
    <mesh file="wrist2_1.obj"/>
    <mesh file="wrist2_2.obj"/>
    <mesh file="wrist3.obj"/>
  </asset>

  <worldbody>
    <light name="spotlight" mode="targetbodycom" target="wrist_2_link" pos="0 -1 2"/>
    <body name="base" quat="0 0 0 -1" childclass="ur5e">
      <inertial mass="4.0" pos="0 0 0" diaginertia="0.00443333156 0.00443333156 0.0072"/>
      <geom mesh="base_0" material="black" class="visual"/>
      <geom mesh="base_1" material="jointgray" class="visual"/>
      <body name="shoulder_link" pos="0 0 0.163">
        <inertial mass="3.7" pos="0 0 0" diaginertia="0.0102675 0.0102675 0.00666"/>
        <joint name="shoulder_pan_joint" class="size3" axis="0 0 1"/>
        <geom mesh="shoulder_0" material="urblue" class="visual"/>
        <geom mesh="shoulder_1" material="black" class="visual"/>
        <geom mesh="shoulder_2" material="jointgray" class="visual"/>
        <geom class="collision" size="0.06 0.06" pos="0 0 -0.04"/>
        <body name="upper_arm_link" pos="0 0.138 0" quat="1 0 1 0">
          <inertial mass="8.393" pos="0 0 0.2125" diaginertia="0.133886 0.133886 0.0151074"/>
          <joint name="shoulder_lift_joint" class="size3"/>
          <geom mesh="upperarm_0" material="linkgray" class="visual"/>
          <geom mesh="upperarm_1" material="black" class="visual"/>
          <geom mesh="upperarm_2" material="jointgray" class="visual"/>
          <geom mesh="upperarm_3" material="urblue" class="visual"/>
          <geom class="collision" pos="0 -0.04 0" quat="1 1 0 0" size="0.06 0.06"/>
          <geom class="collision" size="0.05 0.2" pos="0 0 0.2"/>
          <body name="forearm_link" pos="0 -0.131 0.425">
            <inertial mass="2.275" pos="0 0 0.196" diaginertia="0.0311796 0.0311796 0.004095"/>
            <joint name="elbow_joint" class="size3_limited"/>
            <geom mesh="forearm_0" material="urblue" class="visual"/>
            <geom mesh="forearm_1" material="linkgray" class="visual"/>
            <geom mesh="forearm_2" material="black" class="visual"/>
            <geom mesh="forearm_3" material="jointgray" class="visual"/>
            <geom class="collision" pos="0 0.08 0" quat="1 1 0 0" size="0.055 0.06"/>
            <geom class="collision" size="0.038 0.19" pos="0 0 0.2"/>
            <body name="wrist_1_link" pos="0 0 0.392" quat="1 0 1 0">
              <inertial mass="1.219" pos="0 0.127 0" diaginertia="0.0025599 0.0025599 0.0021942"/>
              <joint name="wrist_1_joint" class="size1"/>
              <geom mesh="wrist1_0" material="black" class="visual"/>
              <geom mesh="wrist1_1" material="urblue" class="visual"/>
              <geom mesh="wrist1_2" material="jointgray" class="visual"/>
              <geom class="collision" pos="0 0.05 0" quat="1 1 0 0" size="0.04 0.07"/>
              <body name="wrist_2_link" pos="0 0.127 0">
                <inertial mass="1.219" pos="0 0 0.1" diaginertia="0.0025599 0.0025599 0.0021942"/>
                <joint name="wrist_2_joint" axis="0 0 1" class="size1"/>
                <geom mesh="wrist2_0" material="black" class="visual"/>
                <geom mesh="wrist2_1" material="urblue" class="visual"/>
                <geom mesh="wrist2_2" material="jointgray" class="visual"/>
                <geom class="collision" size="0.04 0.06" pos="0 0 0.04"/>
                <geom class="collision" pos="0 0.02 0.1" quat="1 1 0 0" size="0.04 0.04"/>
                <body name="wrist_3_link" pos="0 0 0.1">
                  <inertial mass="0.1889" pos="0 0.0771683 0" quat="1 0 0 1" diaginertia="0.000132134 9.90863e-05 9.90863e-05"/>
                  <joint name="wrist_3_joint" class="size1"/>
                  <geom material="linkgray" mesh="wrist3" class="visual"/>
                  <geom class="eef_collision" pos="0 0.08 0" quat="1 1 0 0" size="0.04 0.02"/>
                  <site name="attachment_site" pos="0 0.1 0" quat="-1 1 0 0"/>
                </body>
              </body>
            </body>
          </body>
        </body>
      </body>
    </body>
  </worldbody>

  <actuator>
    <general class="size3" name="shoulder_pan" joint="shoulder_pan_joint"/>
    <general class="size3" name="shoulder_lift" joint="shoulder_lift_joint"/>
    <general class="size3_limited" name="elbow" joint="elbow_joint"/>
    <general class="size1" name="wrist_1" joint="wrist_1_joint"/>
    <general class="size1" name="wrist_2" joint="wrist_2_joint"/>
    <general class="size1" name="wrist_3" joint="wrist_3_joint"/>
  </actuator>

  <keyframe>
    <key name="home" qpos="-1.5708 -1.5708 1.5708 -1.5708 -1.5708 0" ctrl="-1.5708 -1.5708 1.5708 -1.5708 -1.5708 0"/>
  </keyframe>
</mujoco>

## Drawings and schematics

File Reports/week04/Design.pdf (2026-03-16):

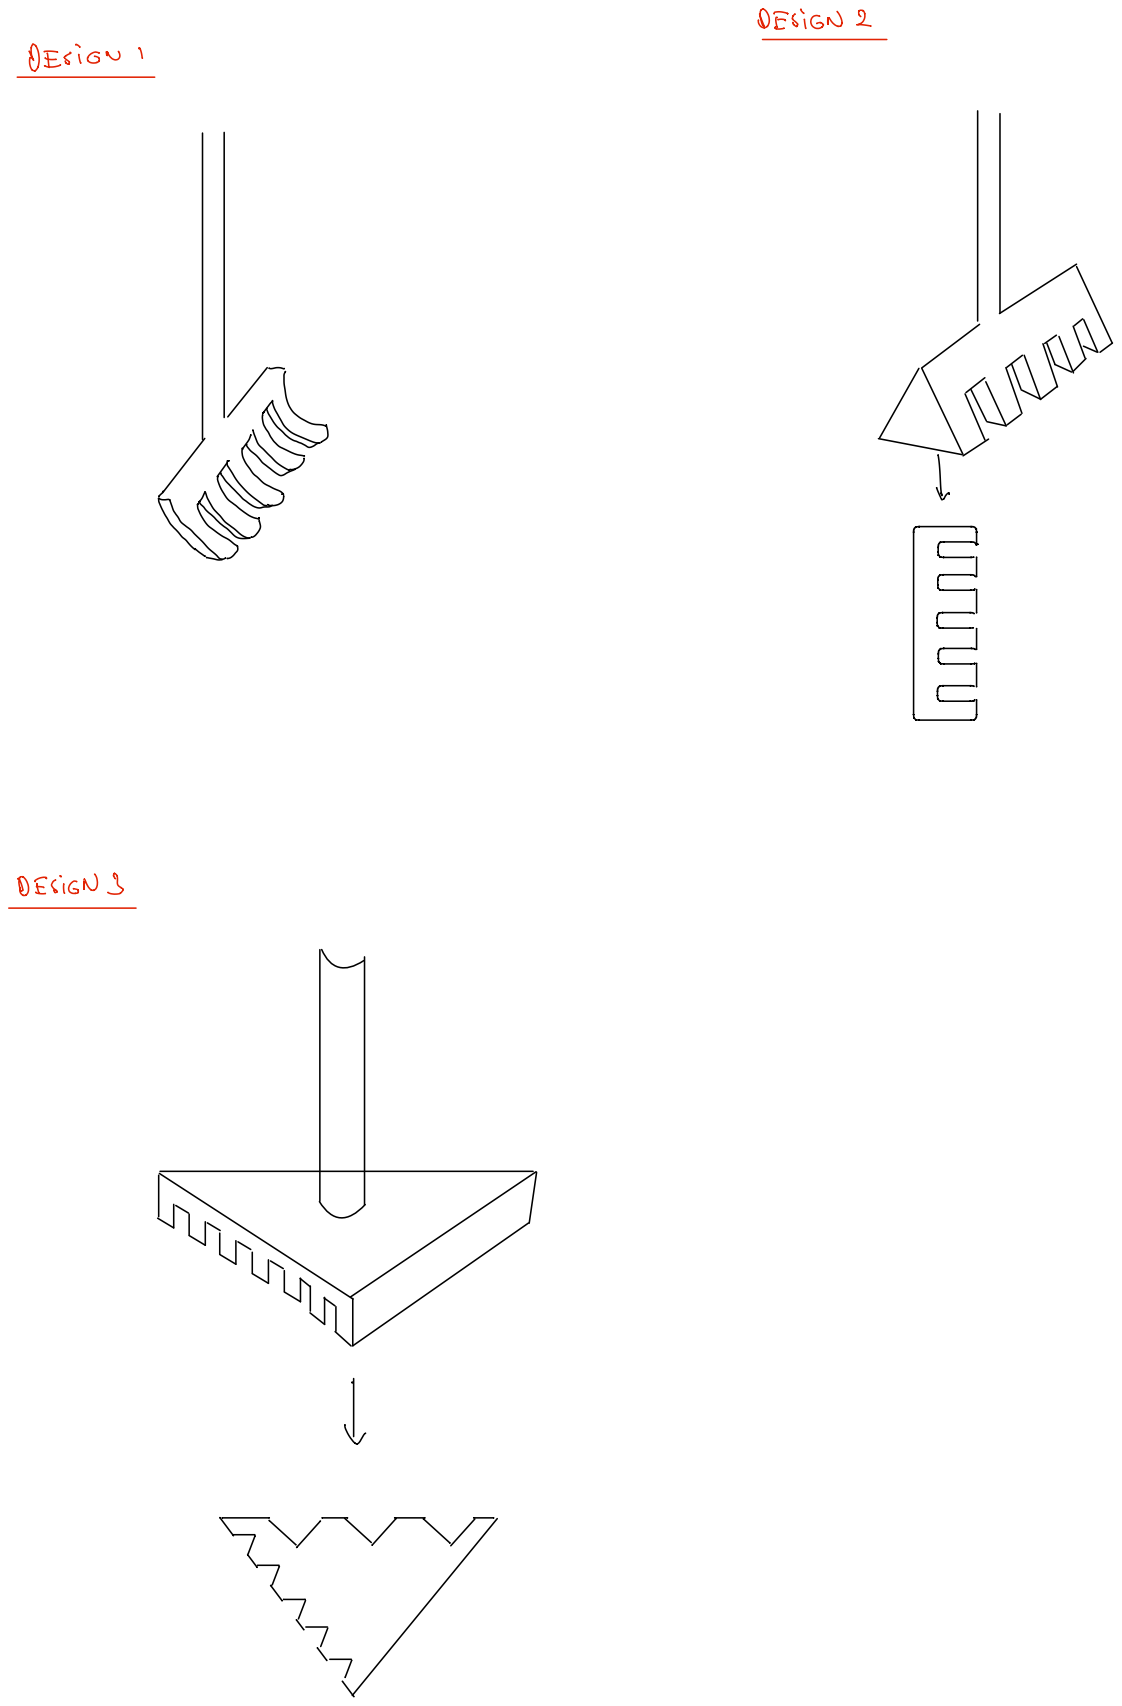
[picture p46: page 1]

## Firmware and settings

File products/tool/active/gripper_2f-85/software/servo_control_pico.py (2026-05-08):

from machine import Pin, PWM
import time
import sys
import select

class DualServoController:
    def __init__(self, pin_left=16, pin_right=17, freq=50, min_us=500, max_us=2500, max_angle=270):
        """
        Initializes the dual servo controller for 270-degree servos.
        Left servo is on pin 16, Right servo is on pin 17.
        """
        self.freq = freq
        self.min_us = min_us
        self.max_us = max_us
        self.max_angle = max_angle
        
        # Initialize PWM objects
        self.servo_left = PWM(Pin(pin_left))
        self.servo_right = PWM(Pin(pin_right))
        
        self.servo_left.freq(self.freq)
        self.servo_right.freq(self.freq)

    def _angle_to_duty(self, angle):
        """Converts an angle in degrees to a 16-bit PWM duty cycle."""
        # Clamp angle between 0 and max_angle
        angle = max(0, min(angle, self.max_angle))
        
        # Map angle to pulse width in microseconds
        pulse_us = self.min_us + (angle / self.max_angle) * (self.max_us - self.min_us)
        
        # Convert pulse width to 16-bit duty cycle (0-65535)
        period_us = 1000000 // self.freq
        duty = int((pulse_us / period_us) * 65535)
        return duty

    def set_angles(self, theta_left, theta_right):
        """Applies specific angles to the left and right servos."""
        self.servo_left.duty_u16(self._angle_to_duty(theta_left))
        self.servo_right.duty_u16(self._angle_to_duty(theta_right))

    def deinit(self):
        """Turns off the PWM signal, allowing the servos to go limp."""
        self.servo_left.deinit()
        self.servo_right.deinit()

# ==========================================
# Terminal Control Execution
# ==========================================

def run_terminal_control():
    # Initialize the gripper
    gripper = DualServoController(pin_left=16, pin_right=17)
    
    # 1500 us corresponds exactly to 135 degrees on a 270-degree servo 
    # (Range: 500us to 2500us)
    center_angle = 135.0
    
    angle_left = center_angle
    angle_right = center_angle
    
    # Send to starting position
    gripper.set_angles(angle_left, angle_right)
    
    print("--- Active Gripper Terminal Control ---")
    print("Status: Centered at 1500 us (135°)")
    print("Controls:")
    print("  [ w ] : Right CCW (+), Left CW (-)")
    print("  [ s ] : Right CW (-), Left CCW (+)")
    print("  [ q ] : Quit and power down servos")
    print("-" * 39)
    
    # Set up the poll object to read terminal input without blocking the loop
    poll_obj = select.poll()
    poll_obj.register(sys.stdin, select.POLLIN)
    
    try:
        while True:
            # Check if there is a character waiting in the terminal
            if poll_obj.poll(0):
                ch = sys.stdin.read(1).lower() # Read and convert to lowercase
                
                if ch == 'w':  
                    # 'w' key pressed
                    angle_right += 2  # Counter-Clockwise
                    angle_left -= 2   # Clockwise
                    
                elif ch == 's':  
                    # 's' key pressed
                    angle_right -= 2  # Clockwise
                    angle_left += 2   # Counter-Clockwise
                
                elif ch == 'q':
                    print("Quitting sequence initiated...")
                    break
                
                # Apply Constraints: Maximum +/- 20 degrees from the center position
                angle_right = max(center_angle - 20, min(angle_right, center_angle + 20))
                angle_left = max(center_angle - 20, min(angle_left, center_angle + 20))
                
                # Execute the move
                gripper.set_angles(angle_left, angle_right)
                
                # Print the live status
                print(f"Left Servo: {angle_left:.1f}° | Right Servo: {angle_right:.1f}°")
                
            # A tiny sleep to prevent the loop from hogging the CPU
            time.sleep(0.01)
            
    except KeyboardInterrupt:
        print("\nProgram interrupted by user.")
        
    finally:
        # Always clean up the PWM signals when done
        gripper.deinit()
        print("Servos powered down safely.")

# Run the script
if __name__ == "__main__":
    run_terminal_control()

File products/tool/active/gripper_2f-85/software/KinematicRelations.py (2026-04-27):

import numpy as np
import matplotlib.pyplot as plt


# ============================================================
# 1) GEOMETRY VALUES - CHANGE THESE ACCORDING TO YOUR SYSTEM
# ============================================================

a1 = 100.0      # link a1 length
a2 = 80.0       # link a2 length
a3 = 120.0      # link a3 length

cx = 50.0       # horizontal distance OA
cy = 40.0       # vertical distance OD

e1 = 20.0       # horizontal offset for orange point
d1 = 30.0       # orange point distance from point C

gamma_deg = 90.0
gamma = np.deg2rad(gamma_deg)

# Choose mechanism assembly branch: +1 or -1
BRANCH_THETA1_INPUT = +1
BRANCH_THETA3_INPUT = +1

# Sweep ranges for plots
theta1_min_deg = 0.0
theta1_max_deg = 180.0

theta3_min_deg = 0.0
theta3_max_deg = 180.0

N = 1000


# ============================================================
# 2) BASIC FUNCTIONS
# ============================================================

def rad2deg_unwrap(angle_rad):
    return np.rad2deg(np.unwrap(angle_rad))


def compute_L(theta2, theta3):
    """
    Calculates Lx, Ly, and L.
    Angles must be in radians.
    """
    Lx = e1 + a3 * np.cos(theta3) + d1 * np.cos(gamma + theta2 - np.pi)
    Ly = cy + a3 * np.sin(theta3) + d1 * np.sin(gamma + theta2 - np.pi)
    L = np.sqrt(Lx**2 + Ly**2)
    return Lx, Ly, L


def solve_from_theta1(theta1, branch=+1):
    """
    Input: theta1 in radians
    Output: theta2, theta3, Lx, Ly, L, valid
    """

    theta1 = np.asarray(theta1)

    C1 = cx + a1 * np.cos(theta1)
    C2 = a1 * np.sin(theta1) - cy

    d = np.sqrt(C1**2 + C2**2)
    phi = np.arctan2(C2, C1)

    arg = (a3**2 - a2**2 - d**2) / (2 * a2 * d)

    valid = (d > 1e-9) & (arg >= -1.0) & (arg <= 1.0)
    arg_clip = np.clip(arg, -1.0, 1.0)

    theta2 = phi + branch * np.arccos(arg_clip)

    theta3 = np.arctan2(
        C2 + a2 * np.sin(theta2),
        C1 + a2 * np.cos(theta2)
    )

    Lx, Ly, L = compute_L(theta2, theta3)

    theta2 = np.where(valid, theta2, np.nan)
    theta3 = np.where(valid, theta3, np.nan)
    Lx = np.where(valid, Lx, np.nan)
    Ly = np.where(valid, Ly, np.nan)
    L = np.where(valid, L, np.nan)

    return theta2, theta3, Lx, Ly, L, valid


def solve_from_theta3(theta3, branch=+1):
    """
    Input: theta3 in radians
    Output: theta1, theta2, Lx, Ly, L, valid
    """

    theta3 = np.asarray(theta3)

    K1 = a3 * np.cos(theta3) - cx
    K2 = cy + a3 * np.sin(theta3)

    s = np.sqrt(K1**2 + K2**2)
    psi = np.arctan2(K2, K1)

    arg = (s**2 + a2**2 - a1**2) / (2 * a2 * s)

    valid = (s > 1e-9) & (arg >= -1.0) & (arg <= 1.0)
    arg_clip = np.clip(arg, -1.0, 1.0)

    theta2 = psi + branch * np.arccos(arg_clip)

    theta1 = np.arctan2(
        K2 - a2 * np.sin(theta2),
        K1 - a2 * np.cos(theta2)
    )

    Lx, Ly, L = compute_L(theta2, theta3)

    theta1 = np.where(valid, theta1, np.nan)
    theta2 = np.where(valid, theta2, np.nan)
    Lx = np.where(valid, Lx, np.nan)
    Ly = np.where(valid, Ly, np.nan)
    L = np.where(valid, L, np.nan)

    return theta1, theta2, Lx, Ly, L, valid


def is_valid_scalar(valid):
    return bool(np.asarray(valid).item())


# ============================================================
# 3) OPTION 1 - PLOT WHOLE VALUES FOR INPUT THETA1
# ============================================================

def plot_for_input_theta1():
    theta1_deg = np.linspace(theta1_min_deg, theta1_max_deg, N)
    theta1 = np.deg2rad(theta1_deg)

    theta2, theta3, Lx, Ly, L, valid = solve_from_theta1(
        theta1,
        branch=BRANCH_THETA1_INPUT
    )

    fig, ax = plt.subplots(2, 1, figsize=(10, 8), sharex=True)

    ax[0].plot(theta1_deg, theta1_deg, label=r"$\theta_1$")
    ax[0].plot(theta1_deg, rad2deg_unwrap(theta2), label=r"$\theta_2$")
    ax[0].plot(theta1_deg, rad2deg_unwrap(theta3), label=r"$\theta_3$")
    ax[0].set_ylabel("Angle (deg)")
    ax[0].set_title(r"Whole Solution for Input $\theta_1$")
    ax[0].grid(True)
    ax[0].legend()

    ax[1].plot(theta1_deg, Lx, label=r"$L_x$")
    ax[1].plot(theta1_deg, Ly, label=r"$L_y$")
    ax[1].set_xlabel(r"Input $\theta_1$ (deg)")
    ax[1].set_ylabel("Length / Position")
    ax[1].grid(True)
    ax[1].legend()

    plt.tight_layout()
    plt.show()


# ============================================================
# 4) OPTION 2 - PLOT WHOLE VALUES FOR INPUT THETA3
# ============================================================

def plot_for_input_theta3():
    theta3_deg = np.linspace(theta3_min_deg, theta3_max_deg, N)
    theta3 = np.deg2rad(theta3_deg)

    theta1, theta2, Lx, Ly, L, valid = solve_from_theta3(
        theta3,
        branch=BRANCH_THETA3_INPUT
    )

    fig, ax = plt.subplots(2, 1, figsize=(10, 8), sharex=True)

    ax[0].plot(theta3_deg, rad2deg_unwrap(theta1), label=r"$\theta_1$")
    ax[0].plot(theta3_deg, rad2deg_unwrap(theta2), label=r"$\theta_2$")
    ax[0].plot(theta3_deg, theta3_deg, label=r"$\theta_3$")
    ax[0].set_ylabel("Angle (deg)")
    ax[0].set_title(r"Whole Solution for Input $\theta_3$")
    ax[0].grid(True)
    ax[0].legend()

    ax[1].plot(theta3_deg, Lx, label=r"$L_x$")
    ax[1].plot(theta3_deg, Ly, label=r"$L_y$")
    ax[1].set_xlabel(r"Input $\theta_3$ (deg)")
    ax[1].set_ylabel("Length / Position")
    ax[1].grid(True)
    ax[1].legend()

    plt.tight_layout()
    plt.show()


# ============================================================
# 5) OPTION 3 - GIVEN THETA3, WRITE THETA1 AND LX
# ============================================================

def value_from_theta3():
    theta3_input_deg = float(input("Enter theta3 input in degrees: "))

    theta3 = np.deg2rad(theta3_input_deg)

    theta1, theta2, Lx, Ly, L, valid = solve_from_theta3(
        theta3,
        branch=BRANCH_THETA3_INPUT
    )

    if not is_valid_scalar(valid):
        print("\nNo valid mechanism solution for this theta3.")
        return

    print("\nResult for given theta3:")
    print("--------------------------------")
    print(f"Input theta3 = {theta3_input_deg:.4f} deg")
    print(f"theta1       = {float(np.rad2deg(theta1)):.4f} deg")
    print(f"theta2       = {float(np.rad2deg(theta2)):.4f} deg")
    print(f"Lx           = {float(Lx):.4f}")
    print(f"Ly           = {float(Ly):.4f}")
    print(f"L            = {float(L):.4f}")


# ============================================================
# 6) OPTION 4 - GIVEN THETA1, WRITE THETA3 AND LX
# ============================================================
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

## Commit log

2026-03-06 ur5e cad file and week 2 meeting minutes added
2026-03-09 Adding my Zen art gripper design
2026-03-11 added zentool stl file
    [ZenToolBaseV1.stl]
2026-03-14 Finished first version of 4 Sided ZenTool with 3 usable sides, added very basic Mujoco simulation python file
    To do: strengthen ZenTool, do meaningfull things with Mujoco file, add readme file to Mujoco folder, look into gazebo?
    [ZenTool_4Sided_Assembly_V4.step]
2026-03-16 Added simple pose to pose UR5e Mujoco movement demo
    [base_0.obj, base_1.obj, forearm_0.obj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]
2026-03-16 Added some design ideas for PCB/interface
2026-03-16 organize messy files
    [ZenToolBaseV1.stl]
2026-03-16 A document about how to create a PCB at ROMER is uploaded
    [25mm 2 Flute Endmill.step, BT30-ER32 Collet Holder with Ø25 Facemill.step, BT30-ER32-60 Collet Holder Body.step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]
2026-03-17 Deleted cad_files folder for the third time
    [25mm 2 Flute Endmill.step, BT30-ER32 Collet Holder with Ø25 Facemill.step, BT30-ER32-60 Collet Holder Body.step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]
2026-03-24 Removed print line from mujoco test file
2026-03-30 Added lock mech idea 2 files
    [locking_mechanism_idea_2-Pin1.stl, locking_mechanism_idea_2-PinGuide.stl, locking_mechanism_idea_2-arm_part.stl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]
2026-04-14 Add week 9 progress report to README
    Added a weekly progress report detailing tasks and challenges faced in robot arm control, optimization of mechanisms, and toolbox design.
2026-04-14 Revise week 9 report with project updates
    Updated the README with progress on robot arm control, toolbox design, and charging options.
2026-04-14 Revise week 9 progress report in README
    Updated the README to reflect progress on the robot arm control and other projects, including optimization details and design concepts.
2026-04-14 i forgot what i did
    [locking_mechanism_idea_2 - Pin1.stl, locking_mechanism_idea_2 - PinGuide.stl, locking_mechanism_idea_2 - handler_part.stl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]
2026-04-19 Add week 10 report and meeting minutes
    Added weekly report detailing progress on robot arm control, toolbox design, and active tools discussion. Included meeting minutes and design ideas.
2026-04-21 added some temp cad files
    [LeftCap.stl, Part Studio 1 - arm_left.step, Part Studio 1 - arm_right.step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]
2026-04-27 Update README with kinematic relations source code
    Added source code files for kinematic relations derivation.
2026-05-01 Folder structure and products added
    [18650 Battery.STEP, 18650 Battery.x_t, 2f-85_base - 2f-85_base_1.step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]
2026-05-02 reports have been rearranged, week12 report added
    [18650 Battery.STEP, 18650 Battery.x_t, BOM of 2f-85_gripper_assembly.csv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]
2026-05-08 Removed CAD_STL_Files
    [25mm 2 Flute Endmill.step, BT30-ER32 Collet Holder with Ø25 Facemill.step, BT30-ER32-60 Collet Holder Body.step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]
